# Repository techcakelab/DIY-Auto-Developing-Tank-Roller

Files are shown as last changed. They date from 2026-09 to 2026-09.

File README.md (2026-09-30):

# DIY - Auto Developing Tank Roller - Universal Timer



Automatic bi-directional film developing rotator, designed as a **Universal Timer** - no pre-set cycles, manually adjustable time and speed for any type of chemical.
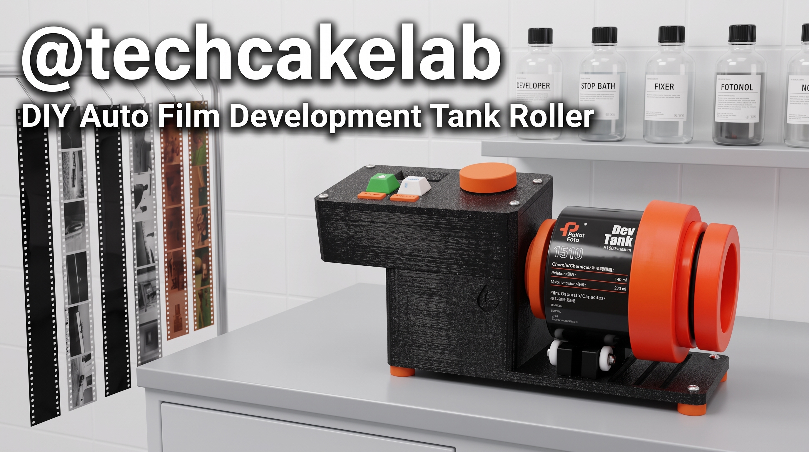
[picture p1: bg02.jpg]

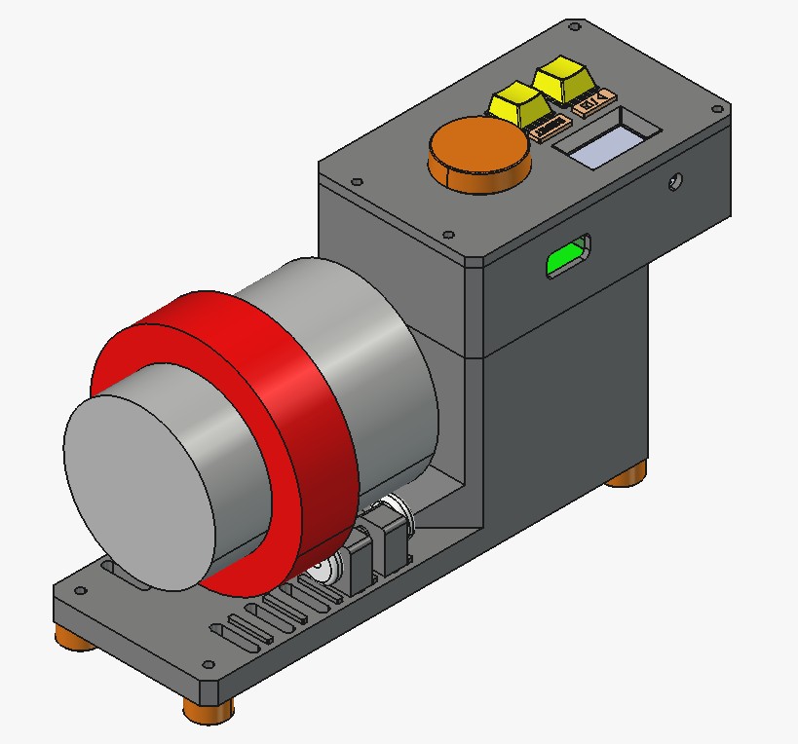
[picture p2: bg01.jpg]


## Features
- **Universal Timer:** Set custom time (0.5 – 30 minutes) and speed (10 – 100 RPM) via KY-040 rotary encoder.
- **Auto Reverse:** Motor runs FWD 10s → pauses 1s → REV 10s → repeats throughout the set time.
- **PID Control:** Maintains stable speed at target RPM using a motor encoder.
- **OLED Display:** Shows remaining time, progress bar, actual / target speed.

## Hardware

### Components
- Microcontroller: **ESP32**
- Motor Driver: **L298N Motor Driver Module**
- Motor: **JGB37-520 DC Gear Motor with Quadrature Encoder**
- Step-Down Converter: **Mini560 5V/5A Buck Converter**
- Display: **OLED SH1106G 128x64** (I2C, address `0x3C`)
- Controls: **KY-040 Rotary Encoder** + **2 Push Buttons**

### Wiring Diagram

| Component | Function | ESP32 Pin |
| :--- | :--- | :--- |
| **Button 1** | Start / Stop | `GPIO 13` |
| **Button 2** | Reset to IDLE | `GPIO 14` |
| **KY-040** | Push Button (SW) – Toggle TIME ↔ RPM | `GPIO 25` |
| **KY-040** | CLK Pulse | `GPIO 32` |
| **KY-040** | DT Pulse | `GPIO 33` |
| **Motor Encoder** | Channel A | `GPIO 34` |
| **Motor Encoder** | Channel B | `GPIO 35` |
| **L298N** | ENA (PWM Speed) | `GPIO 26` |
| **L298N** | IN1 (Direction) | `GPIO 27` |
| **L298N** | IN2 (Direction) | `GPIO 16` |
| **I2C (OLED)** | SDA / SCL | `GPIO 21` (SDA) / `GPIO 22` (SCL) |

> **Important note for L298N module:** In order to control speed with PID, you **MUST remove the jumper (gold/black cap)** plugged into the `ENA` pin (or `ENB` if using port B). After removing the jumper, connect a wire from the `ENA` pin on the L298N board to `GPIO 26` of the ESP32. If you do not remove the jumper, the motor will always run at maximum speed (100%) and you will not be able to adjust the RPM.

## Usage

### SETUP Screen (Before Running)
1. **Rotate KY-040:** Increase/decrease the selected parameter, each click = 15 seconds (for Time) or 1 RPM.
2. **Press SW (KY-040):** Toggle between **TIME** ↔ **RPM**. The `>` sign indicates the currently selected parameter.
3. **Press Button 1:** Start running (START).

### RUNNING Screen (While Running)
- Displays countdown time, progress bar, and actual speed.
- **Rotate KY-040:** Change target RPM on-the-fly (after pressing SW to enter RPM mode).
- **Press SW (KY-040):** Toggle TIME ↔ RPM mode.
- **Press Button 1:** Pause (STOP) → press again to resume.
- **Press Button 2:** Emergency stop and **Full Reset** to SETUP.

### FINISHED Screen (Completed)
- **Press Button 1:** Restart (repeat with the same time and speed).
- **Press Button 2:** Reset to SETUP to reconfigure parameters.

---
**Check out more projects on my channel: [Techcakelab](https://www.youtube.com/@techcakelab)**

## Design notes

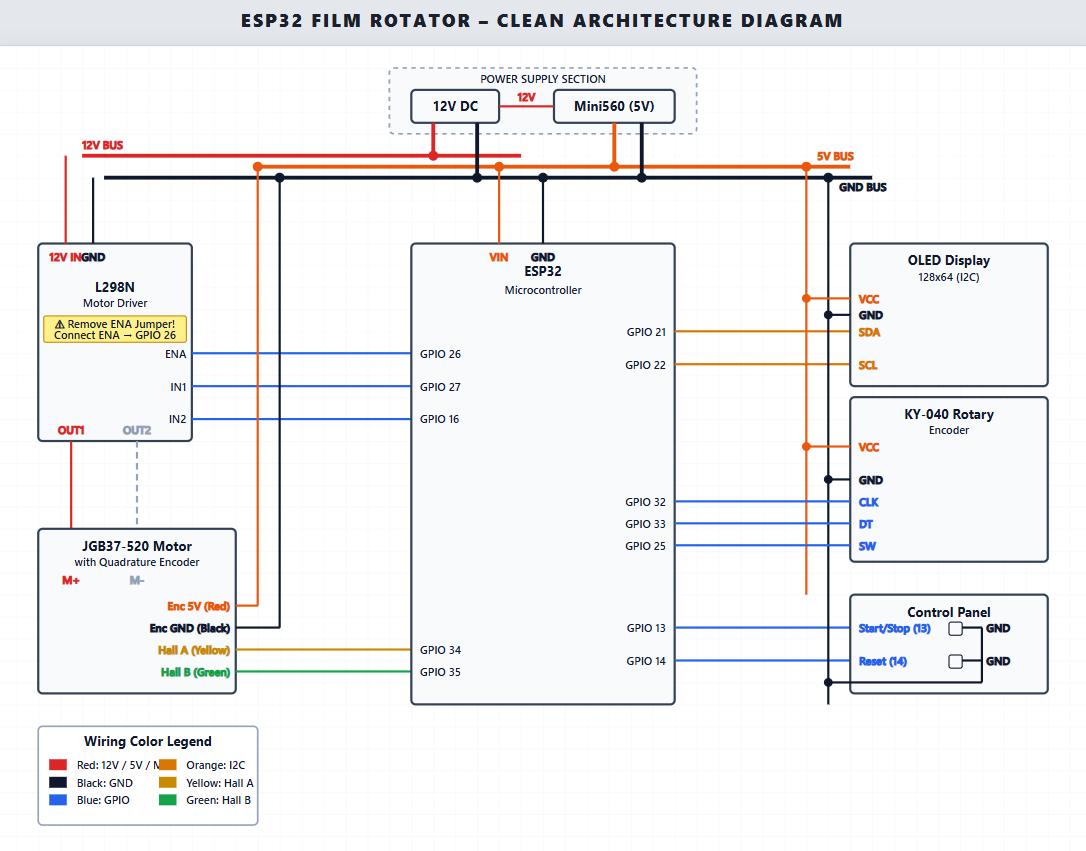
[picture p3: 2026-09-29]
Electronics/Circuit-diagram.jpeg

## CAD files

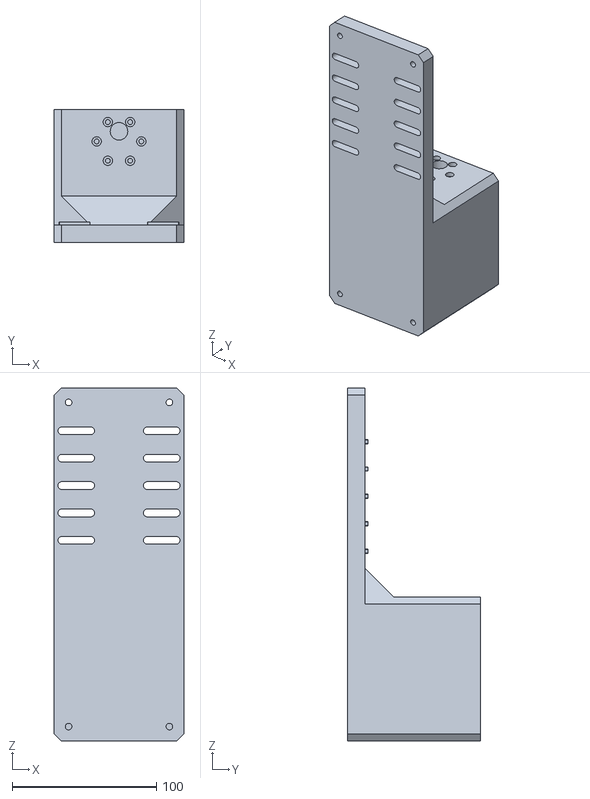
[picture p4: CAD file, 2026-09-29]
3D_models/Main body - qty 1.STL
90.0 x 92.0 x 245.0

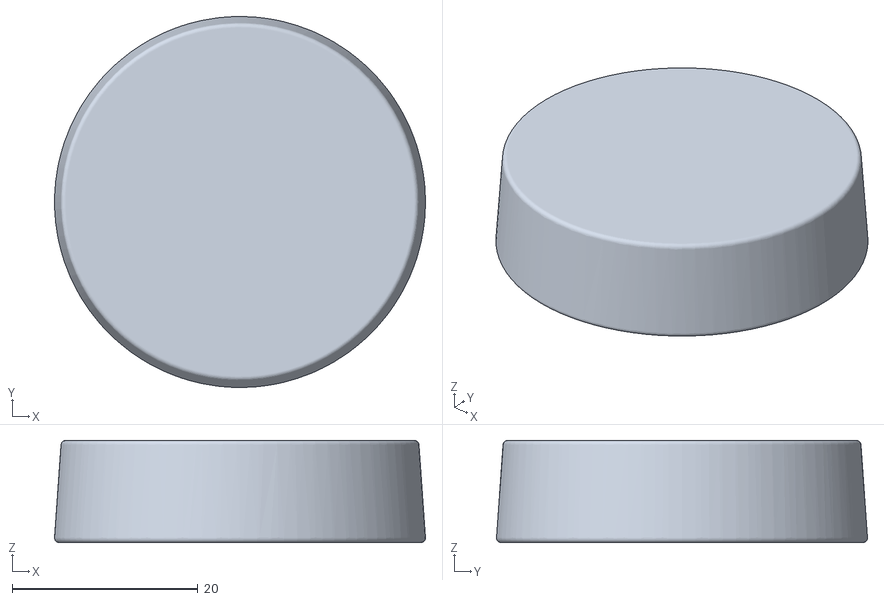
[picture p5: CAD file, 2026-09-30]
3D_models/Knob - qty 1.STL
39.9 x 39.9 x 11.0

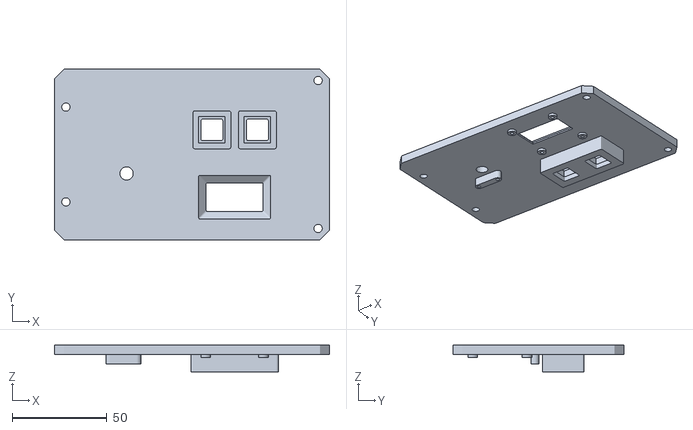
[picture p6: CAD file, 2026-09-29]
3D_models/Ebox cover - qty 1.STL
145.0 x 90.0 x 14.0

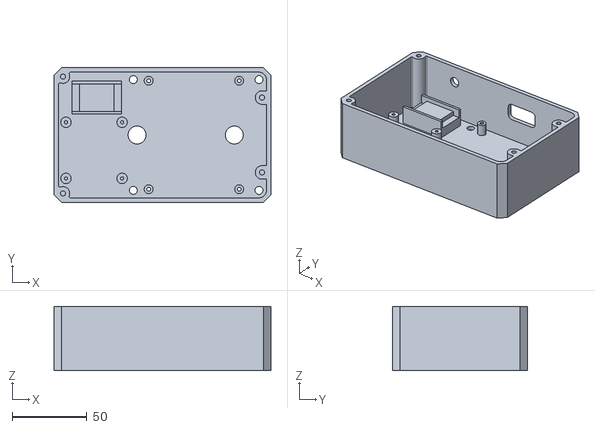
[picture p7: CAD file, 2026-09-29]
3D_models/Ebox - qty 1.STL
145.0 x 90.0 x 43.0

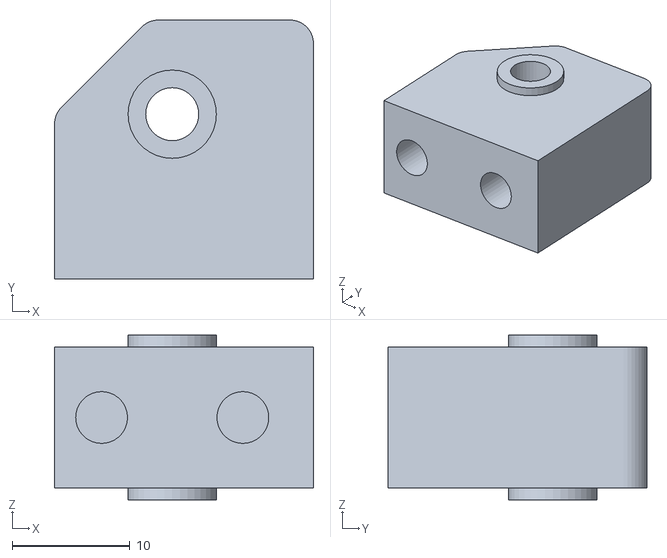
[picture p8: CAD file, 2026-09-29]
3D_models/Holder - qty 4.STL
22.0 x 22.0 x 14.0

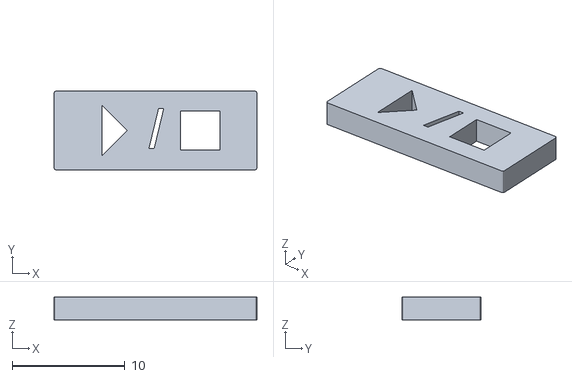
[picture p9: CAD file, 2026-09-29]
3D_models/Text START.STL
18.0 x 7.00 x 2.00

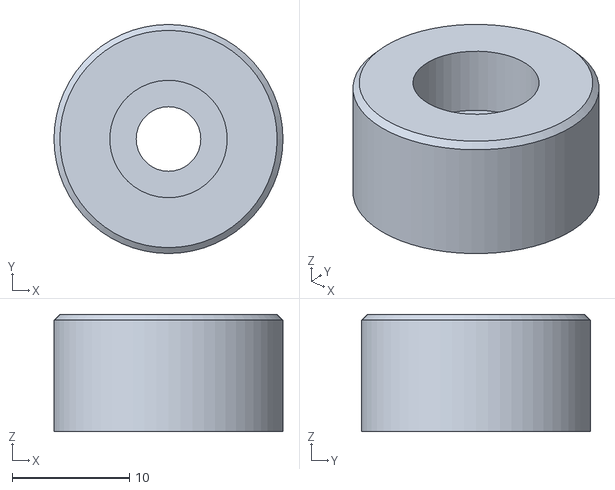
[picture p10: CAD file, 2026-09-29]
3D_models/Foot - qty 4.STL
19.5 x 19.5 x 10.0

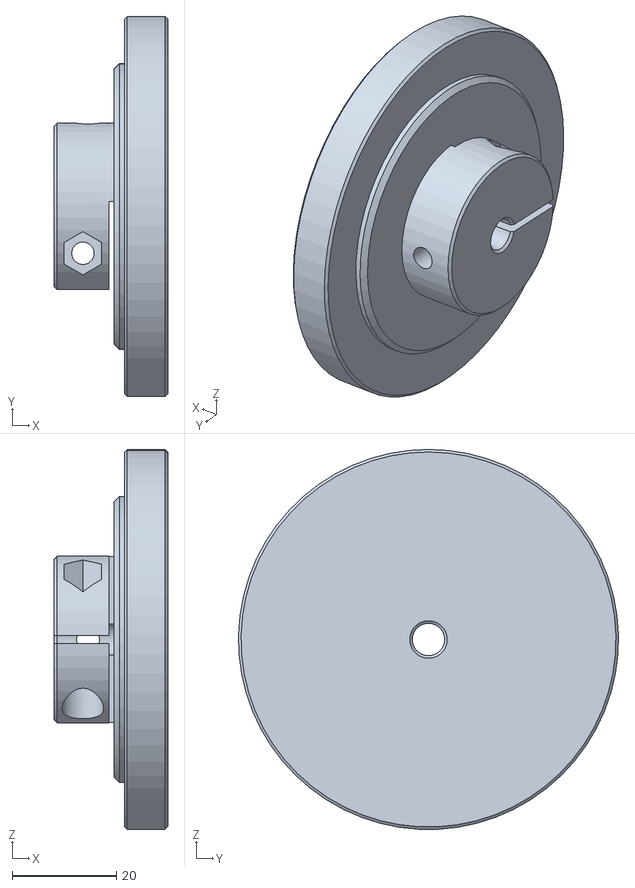
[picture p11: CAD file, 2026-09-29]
3D_models/Rotary disc 2 - qty 1.STL
21.8 x 73.0 x 73.0

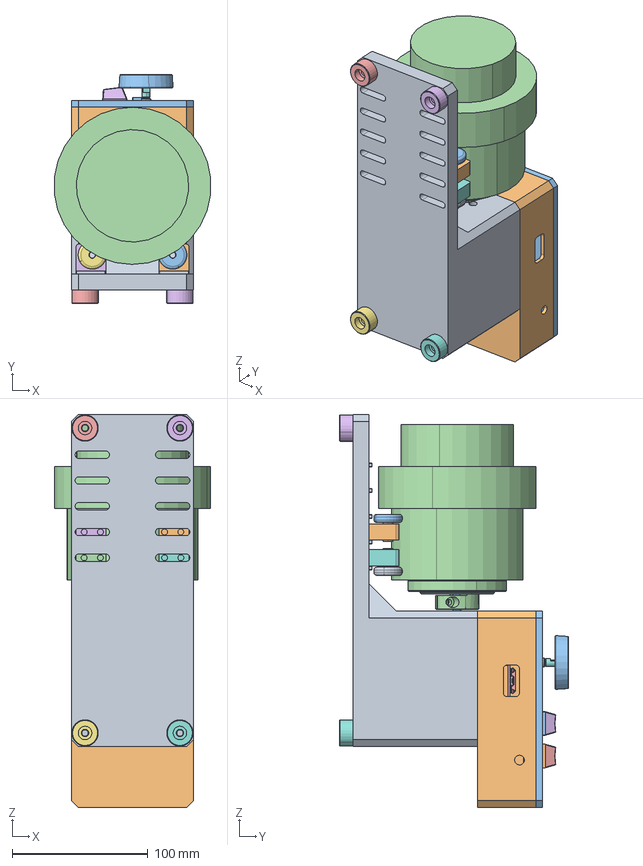
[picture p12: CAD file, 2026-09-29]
3D_models/Auto-Developing-Tank-Roller.FCStd
115.5 x 169.3 x 290.0 mm
Main body - qty 1
Ebox - qty 1
Ebox cover - qty 1
Rotary disc 2 - qty 1
Foot - qty 4
Foot - qty 001
Foot - qty 002
Foot - qty 003
GEARED BODY, MOTOR, JGB37-520
DC MOTOR, JGB37-520
MOTOR SHAFT, JGB37-520
SHAFT COUPLER, JGB37-520
COUPLING BRACKET, GEARED BODY TO DC MOTOR, JGB37-520
PLASTIC COVER, DC MOTOR, JGB37-520
CONNECTION, DC MOTOR, JGB37-520
CONNECTION, DC MOTOR, JGB37-521
pan cross head_am_B18.6.7M - M2 x 0.4 x 25 Type I Cross Recessed PHMS --25N
pan cross head_am_B18.6.7M - M2 x 0.4 x 25 Type I Cross Recessed PHMS --25N001
pan cross head_am_B18.6.7M - M2 x 0.4 x 25 Type I Cross Recessed PHMS --25N002
OLED13 IIC
ESP32_expansion_terminal_board
Cherry Key
Rotary Encoder
D-handle
pcb
2.54 5PIN 90
Knob - qty 1
Holder - qty 4
Roller 5-21
Holder - qty 001
Roller 5-001
Holder - qty 002
Roller 5-002
Holder - qty 003
Roller 5-003
Tank
Key-cap
Key-cap001
Cherry Key001
L298N Motor Driver
DC-DC Step Down Mini 560 PRO
Text START
Text SEMI

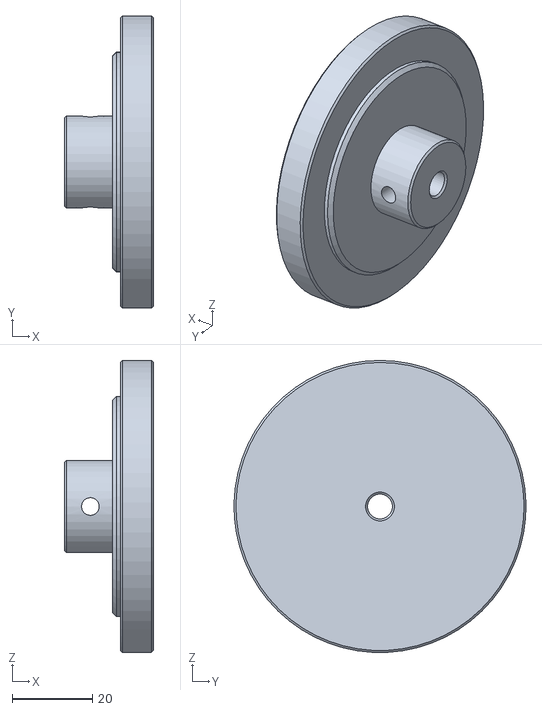
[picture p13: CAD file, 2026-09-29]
3D_models/Rotary disc 1 - qty 1.STL
22.3 x 73.0 x 73.0

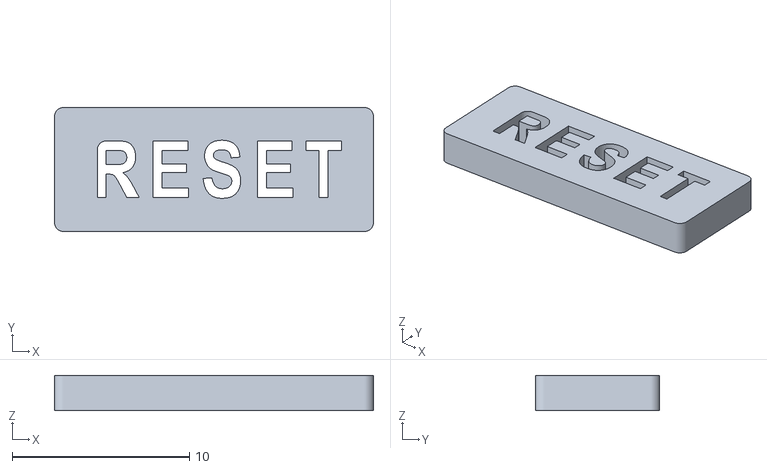
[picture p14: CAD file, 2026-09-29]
3D_models/Text SEMI.STL
18.0 x 7.00 x 2.00

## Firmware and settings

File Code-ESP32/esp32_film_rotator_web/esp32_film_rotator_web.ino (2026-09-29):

#include <Wire.h>
#include <Adafruit_GFX.h>
#include <Adafruit_SH110X.h>

// OLED Configuration
#define SCREEN_WIDTH 128
#define SCREEN_HEIGHT 64
#define OLED_RESET -1
#define OLED_ADDRESS 0x3C
Adafruit_SH1106G display(SCREEN_WIDTH, SCREEN_HEIGHT, &Wire, OLED_RESET);

// L298N Motor Driver Pins
#define ENA_PIN 26
#define IN1_PIN 27
#define IN2_PIN 16
#define PWM_CHANNEL 0

// Hardware Pins
#define BUTTON_PIN    13   // Start / Stop
#define BUTTON2_PIN   14   // Reset
#define ENC_SW_PIN    25   // KY-040 Push button -> toggle TIME <-> RPM
#define ENC_CLK_PIN   32   // KY-040 CLK
#define ENC_DT_PIN    33   // KY-040 DT
#define ENCODER_A_PIN 34   // Motor encoder channel A
#define ENCODER_B_PIN 35   // Motor encoder channel B

// -- Motor timing ----------------------------------------------------------
const unsigned long FWD_TIME_MS  = 10000;
const unsigned long REV_TIME_MS  = 10000;
const unsigned long PAUSE_TIME_MS = 1000;
const float ENCODER_PPR = 1980.0;

// -- PID -------------------------------------------------------------------
float Kp = 10.0, Ki = 5.0, Kd = 0.2;
float integral = 0, lastError = 0;
unsigned long lastPidTime = 0;
long lastEncoderCount = 0;
float currentRPM = 0;
int currentPWM = 0;

// -- Runtime variables -----------------------------------------------------
float TARGET_RPM = 55.0;
unsigned long TOTAL_TIME_MS = 180000UL; // default 3 minutes

// -- Motor encoder ISR -----------------------------------------------------
volatile long encoderCount = 0;
void IRAM_ATTR handleEncoder() {
  if (digitalRead(ENCODER_A_PIN) == digitalRead(ENCODER_B_PIN)) encoderCount++;
  else encoderCount--;
}

// -- KY-040 encoder ISR ----------------------------------------------------
volatile int userEncoderDelta = 0;
void IRAM_ATTR handleUserEncoder() {
  static bool lastClk = HIGH;
  bool clk = digitalRead(ENC_CLK_PIN);
  if (clk != lastClk) {
    if (clk == LOW) {
      if (digitalRead(ENC_DT_PIN) == HIGH) userEncoderDelta++;
      else userEncoderDelta--;
    }
  }
  lastClk = clk;
}

// -- Edit mode -------------------------------------------------------------
enum EditMode { EDIT_TIME, EDIT_RPM };
EditMode editMode = EDIT_TIME;

// -- State machine ---------------------------------------------------------
enum State { IDLE, RUNNING_FWD, PAUSING_FWD, RUNNING_REV, PAUSING_REV, FINISHED };
State currentState = IDLE;

unsigned long processStartTime = 0;
unsigned long stateStartTime = 0;
unsigned long remainingTimeMs = 0;

// -- Debounce --------------------------------------------------------------
bool lastBtnState   = HIGH;
bool lastBtn2State  = HIGH;
bool lastEncSwState = HIGH;
unsigned long lastBtnTime   = 0;
unsigned long lastBtn2Time  = 0;
unsigned long lastEncSwTime = 0;
const unsigned long DEBOUNCE_MS = 200;

// -- Motor helpers ---------------------------------------------------------
void setMotor(int speed, bool forward) {
  if (speed == 0) {
    ledcWrite(ENA_PIN, 0);
    digitalWrite(IN1_PIN, LOW);
    digitalWrite(IN2_PIN, LOW);
  } else {
    ledcWrite(ENA_PIN, speed);
    if (forward) {
      digitalWrite(IN1_PIN, HIGH);
      digitalWrite(IN2_PIN, LOW);
    } else {
      digitalWrite(IN1_PIN, LOW);
      digitalWrite(IN2_PIN, HIGH);
    }
  }
}

void resetPID() {
  integral = 0; lastError = 0; currentPWM = 0;
  noInterrupts(); lastEncoderCount = encoderCount; interrupts();
  lastPidTime = millis();
}

void applyPID(bool forward) {
  unsigned long now = millis();
  unsigned long dt = now - lastPidTime;
  if (dt >= 100) {
    noInterrupts(); long enc = encoderCount; interrupts();
    long delta = abs(enc - lastEncoderCount);
    lastEncoderCount = enc; lastPidTime = now;

    currentRPM = (delta / ENCODER_PPR) * (60000.0 / dt);
    float error = TARGET_RPM - currentRPM;
    integral += error * (dt / 1000.0);
    integral = constrain(integral, -200, 200);
    float derivative = (error - lastError) / (dt / 1000.0);
    lastError = error;

    float output = (Kp * error) + (Ki * integral) + (Kd * derivative);
    currentPWM += (int)output;
    currentPWM = constrain(currentPWM, 0, 4095);
    setMotor(currentPWM > 50 ? currentPWM : 0, forward);
  }
}

void startProcess() {
  currentState = RUNNING_FWD;
  processStartTime = millis();
  stateStartTime = millis();
  remainingTimeMs = TOTAL_TIME_MS;
  resetPID();
}

void stopProcess() {
  currentState = IDLE;
  setMotor(0, true);
  currentRPM = 0;
  integral = 0;
}

// -- OLED helpers ----------------------------------------------------------
void drawBar(int x, int y, int w, int h, float pct) {
  display.drawRect(x, y, w, h, SH110X_WHITE);
  int fill = (int)(constrain(pct, 0, 100) / 100.0 * (w - 2));
  if (fill > 0) display.fillRect(x + 1, y + 1, fill, h - 2, SH110X_WHITE);
}

void updateOLED() {
  display.clearDisplay();
  display.setTextColor(SH110X_WHITE);

  if (currentState == IDLE) {
    // -- Setup Screen ------------------------------------------------------
    display.setTextSize(1);
    display.setCursor(0, 0);
    display.print("FILM ROTATOR  SETUP");
    display.drawLine(0, 9, 128, 9, SH110X_WHITE);

    // Time
    float timeMins = TOTAL_TIME_MS / 60000.0;
    uint8_t m = (uint8_t)timeMins;
    uint8_t s = (uint8_t)((timeMins - m) * 60);

    display.setTextSize(1);
    display.setCursor(0, 13);
    if (editMode == EDIT_TIME) display.print("> TIME:");
    else                       display.print("  TIME:");

    display.setTextSize(2);
    display.setCursor(56, 11);
    display.printf("%02d:%02d", m, s);

    // RPM
    display.setTextSize(1);
    display.setCursor(0, 32);
    if (editMode == EDIT_RPM) display.print("> RPM: ");
    else                      display.print("  RPM: ");

    display.setTextSize(2);
    display.setCursor(56, 30);
    display.printf("%3d", (int)TARGET_RPM);

    // Hint
    display.setTextSize(1);
    display.setCursor(0, 55);
    display.print("SW:switch  BTN1:START");

  } else if (currentState == FINISHED) {
    // -- Finished Screen ---------------------------------------------------
    display.setTextSize(2);
    display.setCursor(10, 16);
    display.print("FINISHED!");
    display.setTextSize(1);
    display.setCursor(10, 50);
    display.print("BTN1 = restart");

  } else {
    // -- Running Screen ----------------------------------------------------
    const char* dirStr = "PAUSE";
    if (currentState == RUNNING_FWD) dirStr = "FWD >>>";
    else if (currentState == RUNNING_REV) dirStr = "<<< REV";

    display.setTextSize(1);
    display.setCursor(0, 0);
    display.print(dirStr);
    display.drawLine(0, 9, 128, 9, SH110X_WHITE);

    // Countdown
    display.setTextSize(2);
    display.setCursor(0, 12);
    uint8_t m = (remainingTimeMs / 1000) / 60;
    uint8_t s = (remainingTimeMs / 1000) % 60;
    display.printf("%02d:%02d", m, s);

    // Progress bar
    float prog = (float)(TOTAL_TIME_MS - remainingTimeMs) / TOTAL_TIME_MS * 100.0;
    drawBar(0, 34, 128, 6, prog);

    // RPM (actual / target)
    display.setTextSize(1);
    display.setCursor(0, 44);
    display.printf("%.1f / %d RPM", currentRPM, (int)TARGET_RPM);

    display.setCursor(0, 55);
    display.print("BTN1=STOP  BTN2=edit RPM");
  }

  display.display();
}

// -------------------------------------------------------------------------
void setup() {
  Serial.begin(115200);

  pinMode(BUTTON_PIN,    INPUT_PULLUP);
  pinMode(BUTTON2_PIN,   INPUT_PULLUP);
  pinMode(ENC_SW_PIN,    INPUT_PULLUP);
  pinMode(ENC_CLK_PIN,   INPUT_PULLUP);
  pinMode(ENC_DT_PIN,    INPUT_PULLUP);
  pinMode(ENCODER_A_PIN, INPUT_PULLUP);
  pinMode(ENCODER_B_PIN, INPUT_PULLUP);

  attachInterrupt(digitalPinToInterrupt(ENCODER_A_PIN), handleEncoder,    CHANGE);
  attachInterrupt(digitalPinToInterrupt(ENC_CLK_PIN),   handleUserEncoder, CHANGE);

  Wire.begin();
  if (!display.begin(OLED_ADDRESS, true)) {
    Serial.println("[ERROR] OLED display not found on I2C (address 0x3C)!");
    Serial.println("Please check SDA/SCL wiring and display power supply.");
  } else {
    Serial.println("[OK] OLED display found and initialized successfully.");
  }

  pinMode(IN1_PIN, OUTPUT);
  pinMode(IN2_PIN, OUTPUT);
  
  // Setup PWM for ENA (ESP32 Core 3.x style)
  ledcAttach(ENA_PIN, 1000, 12); // 1 kHz, 12-bit resolution (0-4095)

  setMotor(0, true);

  updateOLED();
}

void loop() {
  unsigned long now = millis();

  // -- Read KY-040 encoder -----------------------------------------------
  noInterrupts(); int delta = userEncoderDelta; userEncoderDelta = 0; interrupts();
  if (delta != 0) {
    if (editMode == EDIT_TIME) {
      // Adjust by 15 seconds (0.25 minutes)
      float mins = TOTAL_TIME_MS / 60000.0 + delta * 0.25;
      mins = constrain(mins, 0.5, 30.0);
      TOTAL_TIME_MS = (unsigned long)(mins * 60000.0);
    } else {
      TARGET_RPM += delta;
      TARGET_RPM = constrain(TARGET_RPM, 10, 100);
    }
  }

  // -- KY-040 SW Button: toggle TIME <-> RPM mode ------------------------
  bool sw = digitalRead(ENC_SW_PIN);
  if (sw == LOW && lastEncSwState == HIGH && (now - lastEncSwTime > DEBOUNCE_MS)) {
    lastEncSwTime = now;
    editMode = (editMode == EDIT_TIME) ? EDIT_RPM : EDIT_TIME;
  }
  lastEncSwState = sw;

  // -- Button 1: Start / Stop --------------------------------------------
  bool btn = digitalRead(BUTTON_PIN);
  if (btn == LOW && lastBtnState == HIGH && (now - lastBtnTime > DEBOUNCE_MS)) {
    lastBtnTime = now;
    if (currentState == IDLE || currentState == FINISHED) startProcess();
    else stopProcess();
  }
  lastBtnState = btn;

  // -- Button 2: Reset to IDLE from anywhere -----------------------------
  bool btn2 = digitalRead(BUTTON2_PIN);
  if (btn2 == LOW && lastBtn2State == HIGH && (now - lastBtn2Time > DEBOUNCE_MS)) {
    lastBtn2Time = now;
    stopProcess(); // stop motor and go to IDLE
    editMode = EDIT_TIME;
  }
  lastBtn2State = btn2;

  // -- State Machine -----------------------------------------------------
  if (currentState != IDLE && currentState != FINISHED) {
    unsigned long elapsed = now - processStartTime;

    if (elapsed >= TOTAL_TIME_MS) {
      setMotor(0, true);
      currentState = FINISHED;
      currentRPM = 0;
    } else {
      remainingTimeMs = TOTAL_TIME_MS - elapsed;
      unsigned long inState = now - stateStartTime;

      switch (currentState) {
        case RUNNING_FWD:
          if (inState >= FWD_TIME_MS) {
            currentState = PAUSING_FWD;
            stateStartTime = now;
            setMotor(0, true);
            currentRPM = 0;
          } else applyPID(true);
          break;

        case PAUSING_FWD:
          if (inState >= PAUSE_TIME_MS) {
            currentState = RUNNING_REV;
            stateStartTime = now;
            resetPID();
          }
          break;

        case RUNNING_REV:
          if (inState >= REV_TIME_MS) {
            currentState = PAUSING_REV;
            stateStartTime = now;
            setMotor(0, true);
            currentRPM = 0;
          } else applyPID(false);
          break;

        case PAUSING_REV:
          if (inState >= PAUSE_TIME_MS) {
            currentState = RUNNING_FWD;
            stateStartTime = now;
            resetPID();
          }
          break;

        default: break;
      }
    }
  }

  // -- Update OLED 4 times/second ----------------------------------------
  static unsigned long lastOled = 0;
  if (now - lastOled >= 250) {
    lastOled = now;
    updateOLED();
  }
}
